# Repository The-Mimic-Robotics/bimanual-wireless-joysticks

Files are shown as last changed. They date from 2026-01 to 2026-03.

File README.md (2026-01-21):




<h2>Summary</h2>

This project enables the high-precision wireless control of MISC, two robotic arms, using Feetech STS smart motors. By utilizing a distributed architecture of ESP32 microcontrollers, the system translates physical joystick inputs into real-time robotic movement, with XBOX controller protocol emulation.

It is designed for low latency and high reliability, featuring a central hub that aggregates data from multiple peripheral devices to synchronize motor behavior across a daisy-chained serial bus.

<h2>Features</h2>

<h3>Multi-Protocol Wireless Control</h3>

Leverages **ESP-NOW** to transmit joystick data from peripheral ESP32-C3 SuperMini units to a central hub with sub-second processing latency and **Bluetooth Low Energy (BLE)** to relay the combined data to a workstation.

<h3>XBOX Protocol Emulation</h3>

The central ESP32 Node-MCU formats incoming data to impersonate standard XBOX controller protocols using **jsTest**, allowing the robotic inputs to be recognized by standard simulation and gaming software.

<h3>Daisy-Chained Smart Servos</h3>

Controls a series of 4 **Feetech STS smart motors** via a single UART interface, maximizing hardware efficiency while maintaining individual motor addressability. Only visible [here](https://projectgrid.net/museum/mimicbrach)!

<h3>Precision Calibration</h3>

Includes a dedicated calibration suite using potentiometers to record non-zero offsets and an algorithmic safety layer to enforce the unique range of motion for each specific motor.

<h3>Functional Block Architecture</h3>

Components are grouped into logical clusters (Power, Processing, IO), significantly reducing the "Spaghetti Ratsnest" effect and shortening signal paths for improved electromagnetic compatibility (EMC).

<h3>Advanced Power Filtering</h3>

Features a precision decoupling strategy with 0.1uF and 22uF local energy reservoirs placed at the physical limit of the VCC pins to prevent high-frequency noise and random system crashes.

<h3>Thermal Heat Sinking</h3>

Utilizes strategic copper pours and ground planes to act as a passive heat sink for the L7805 regulator, preventing thermal shutdown in high-current applications.

<h3>Fabrication-Ready Constraints</h3>

Incorporates strict design rules for copper-to-edge clearances and mechanical "finger space," ensuring the board is both manufacturable and usable in real-world enclosures.

<h2>Technical Implementation</h2>

The architecture is split between input capture and central processing to minimize cumulative latency:

<h3>Peripheral Input (ESP32-C3 SuperMini)</h3>

Acts as the peripheral device for reading analog joystick inputs. It handles the initial signal processing and transmits the data packets wirelessly to the hub. It also supports a serial bridge for real-time robotic arm simulations.

<h3>Central Hub (ESP32 Node-MCU)</h3>

Aggregates data from both peripheral arms, handles the logic for motor ID deduction in daisy-chained configurations, and outputs the final formatted control signals.

<h3>Hardware & Power Management</h3>

* **Communication:** UART protocol for high-speed motor telemetry.
* **Power:** Powered by a programmable DC supply outputting **7.4V @ 2A**, optimized for the peak current draw of 4 smart motors.
* **Latency Control:** Rigorous experimental tuning using 3D-printed mini robot arms to ensure 100% mirroring of user inputs.

<h3>Functional Grouping & Routing</h3>

To avoid a "Spaghetti" ratsnest, MicroNode utilizes functional block grouping. All capacitors and resistors for the ESP32 are kept in close proximity to the MCU, while the L7805 and its filter capacitors form a dedicated power block. Components are rotated to minimize crossing "ratsnest" lines, resulting in shorter, straighter traces.

<h3>Local Energy Reservoirs</h3>

Electrical stability is maintained by placing the 0.1uF decoupling capacitor as close as physically possible to the VCC pin of the ESP32. This creates the shortest possible VCC-Capacitor-Ground loop, allowing the capacitor to filter high-frequency noise effectively.

<h3>Edge Clearance Constraints</h3>

To prevent the fabrication house's router bits from clipping copper traces, a "Copper to Edge" clearance of 0.5mm (20 mils) is enforced via KiCad’s Design Rules (Board Setup > Constraints). This protects the integrity of the yellow Edge.Cuts boundary during the milling process.

<h3>Thermal Management (L7805)</h3>

The L7805 linear regulator is given "breathing room" to convert excess voltage into heat safely. Instead of smothering it between larger components, it is connected to a large Ground Plane (Copper Pour) which pulls heat away from the regulator body.

<h3>Mechanical & 3D Verification</h3>

The KiCad 3D Viewer (Alt + 3) is used to verify "Finger Space." This ensures that connectors are not placed so close together that cables cannot be plugged in, and that tall components do not obstruct mechanical access.

<h2>Installation</h2>

Clone the project repository

```bash
git clone https://github.com/The-Mimic-Robotics/bimanual-wireless-joysticks.git
```

<h3>Peripheral (ESP32-C3 SuperMini)</h3>

Install the libraries

Upload Peripheral Code

1. Connect the ESP32-C3 SuperMini.
2. Change the BOARD_ID integer value!
3. Flash the device.

<h3>Central Hub (ESP32 Node-MCU)</h3>

Install the libraries

Upload Central Hub Code

1. Connect the ESP32 Node-MCU.
2. Flash the device.

<h3>Smart Motors Controller</h3>

Install the libraries

Upload [Code](https://projectgrid.net/museum/mimicbrach)

1. Connect the desired micro-controller
2. Flash the device.

<h2>Authors</h2>

|Maintainer|Gabrel Oliveira da Silva
|---|---
|Status|Maintained/Active
|Web-Page|https://projectgrid.net
|Patch Work|https://github.com/The-Mimic-Robotics/bimanual-wireless-joysticks/commits?author=gabibdods
|SCM|https://github.com/The-Mimic-Robotics/bimanual-wireless-joysticks.git
|Files|ble_central/, ble_periph/, control_servo/, .tool-versions

|Maintainer|Ashal Patel
|---|---
|Status|Maintained/Contributing
|Web-Page|https://portfolio-website-alpha-smoky-75.vercel.app
|Patch Work|https://github.com/The-Mimic-Robotics/bimanual-wireless-joysticks/commits?author=ac-pate
|SCM|https://github.com/The-Mimic-Robotics/bimanual-wireless-joysticks.git
|Files|imu_wt61/

<h2>Album</h2>

<h3>Network of micro-controllers</h3>

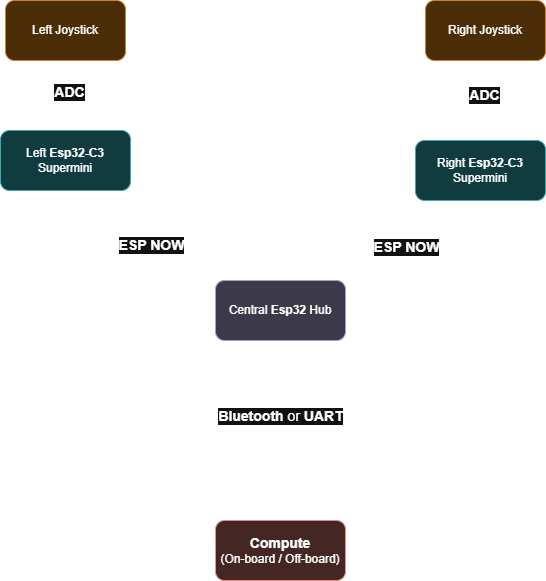
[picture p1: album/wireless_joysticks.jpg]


<h3>And more!</h3>

[Here!](https://projectgrid.net/mimicbrach)

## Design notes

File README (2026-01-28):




## Summary

This project enables the high-precision wireless control of MISC, two robotic arms, using Feetech STS smart motors. By utilizing a distributed architecture of ESP32 microcontrollers, the system translates physical joystick inputs into real-time robotic movement, with XBOX controller protocol emulation.

It is designed for low latency and high reliability, featuring a central hub that aggregates data from multiple peripheral devices to synchronize motor behavior across a daisy-chained serial bus.

## Features

### Multi-Protocol Wireless Control

Leverages **ESP-NOW** to transmit joystick data from peripheral ESP32-C3 SuperMini units to a central hub with sub-second processing latency and **Bluetooth Low Energy (BLE)** to relay the combined data to a workstation.

### BOX Protocol Emulation

The central ESP32 Node-MCU formats incoming data to impersonate standard XBOX controller protocols using **jsTest**, allowing the robotic inputs to be recognized by standard simulation and gaming software.

### Daisy-Chained Smart Servos

Controls a series of 4 **Feetech STS smart motors** via a single UART interface, maximizing hardware efficiency while maintaining individual motor addressability. Only visible [here](https://projectgrid.net/museum/mimicbrach)!

### Precision Calibration

Includes a dedicated calibration suite using potentiometers to record non-zero offsets and an algorithmic safety layer to enforce the unique range of motion for each specific motor.

### Functional Block Architecture

Components are grouped into logical clusters (Power, Processing, IO), significantly reducing the "Spaghetti Ratsnest" effect and shortening signal paths for improved electromagnetic compatibility (EMC).

### Advanced Power Filtering

Features a precision decoupling strategy with 0.1uF and 22uF local energy reservoirs placed at the physical limit of the VCC pins to prevent high-frequency noise and random system crashes.

### Thermal Heat Sinking

Utilizes strategic copper pours and ground planes to act as a passive heat sink for the L7805 regulator, preventing thermal shutdown in high-current applications.

### Fabrication-Ready Constraints

Incorporates strict design rules for copper-to-edge clearances and mechanical "finger space," ensuring the board is both manufacturable and usable in real-world enclosures.

## Technical Implementation

The architecture is split between input capture and central processing to minimize cumulative latency:

### Peripheral Input (ESP32-C3 SuperMini)

Acts as the peripheral device for reading analog joystick inputs. It handles the initial signal processing and transmits the data packets wirelessly to the hub. It also supports a serial bridge for real-time robotic arm simulations.

### Central Hub (ESP32 Node-MCU)

Aggregates data from both peripheral arms, handles the logic for motor ID deduction in daisy-chained configurations, and outputs the final formatted control signals.

### Hardware & Power Management

* **Communication:** UART protocol for high-speed motor telemetry.
* **Power:** Powered by a programmable DC supply outputting **7.4V @ 2A**, optimized for the peak current draw of 4 smart motors.
* **Latency Control:** Rigorous experimental tuning using 3D-printed mini robot arms to ensure 100% mirroring of user inputs.

### Functional Grouping & Routing

To avoid a "Spaghetti" ratsnest, MicroNode utilizes functional block grouping. All capacitors and resistors for the ESP32 are kept in close proximity to the MCU, while the L7805 and its filter capacitors form a dedicated power block. Components are rotated to minimize crossing "ratsnest" lines, resulting in shorter, straighter traces.

### Local Energy Reservoirs

Electrical stability is maintained by placing the 0.1uF decoupling capacitor as close as physically possible to the VCC pin of the ESP32. This creates the shortest possible VCC-Capacitor-Ground loop, allowing the capacitor to filter high-frequency noise effectively.

### Edge Clearance Constraints

To prevent the fabrication house's router bits from clipping copper traces, a "Copper to Edge" clearance of 0.5mm (20 mils) is enforced via KiCad’s Design Rules (Board Setup > Constraints). This protects the integrity of the yellow Edge.Cuts boundary during the milling process.

### Thermal Management (L7805)

The L7805 linear regulator is given "breathing room" to convert excess voltage into heat safely. Instead of smothering it between larger components, it is connected to a large Ground Plane (Copper Pour) which pulls heat away from the regulator body.

### Mechanical & 3D Verification

The KiCad 3D Viewer (Alt + 3) is used to verify "Finger Space." This ensures that connectors are not placed so close together that cables cannot be plugged in, and that tall components do not obstruct mechanical access.

## Installation

### Clone the project repository

```bash
git clone https://github.com/The-Mimic-Robotics/bimanual-wireless-joysticks.git
```

### Peripheral (ESP32-C3 SuperMini)

#### Install the libraries

#### Upload Peripheral Code

1. Connect the ESP32-C3 SuperMini.
2. Change the BOARD_ID integer value!
3. Flash the device.

### Central Hub (ESP32 Node-MCU)

#### Install the libraries

#### Upload Central Hub Code

1. Connect the ESP32 Node-MCU.
2. Flash the device.

### Smart Motors Controller

#### Install the libraries

#### Upload [Code](https://projectgrid.net/museum/mimicbrach)

1. Connect the desired micro-controller
2. Flash the device.

## Authors

|Maintainer|Gabrel Oliveira da Silva
|---|---
|Status|Maintained/Active
|Web-Page|https://projectgrid.net
|Patch Work|https://github.com/The-Mimic-Robotics/bimanual-wireless-joysticks/commits?author=gabibdods
|SCM|https://github.com/The-Mimic-Robotics/bimanual-wireless-joysticks.git
|Files|ble_central/, ble_periph/, control_servo/, .tool-versions

|Maintainer|Ashal Patel
|---|---
|Status|Maintained/Contributing
|Web-Page|https://portfolio-website-alpha-smoky-75.vercel.app
|Patch Work|https://github.com/The-Mimic-Robotics/bimanual-wireless-joysticks/commits?author=ac-pate
|SCM|https://github.com/The-Mimic-Robotics/bimanual-wireless-joysticks.git
|Files|imu_wt61/

## Album

### Network of micro-controllers



### And more!

[Here!](https://projectgrid.net/mimicbrach)

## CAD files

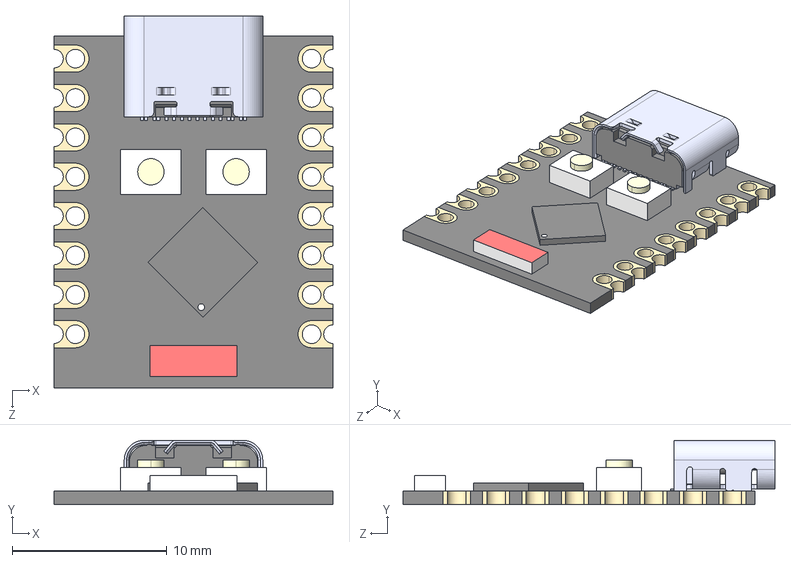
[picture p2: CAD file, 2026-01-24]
teleop_pcb/ESP32-C3_SUPERMINI_TH/ESP32-C3_SUPERMINI_TH.step
18.0 x 4.16 x 24.0 mm
Board c3mini
USB C
components (other)^ESP32-C3 SuperMini

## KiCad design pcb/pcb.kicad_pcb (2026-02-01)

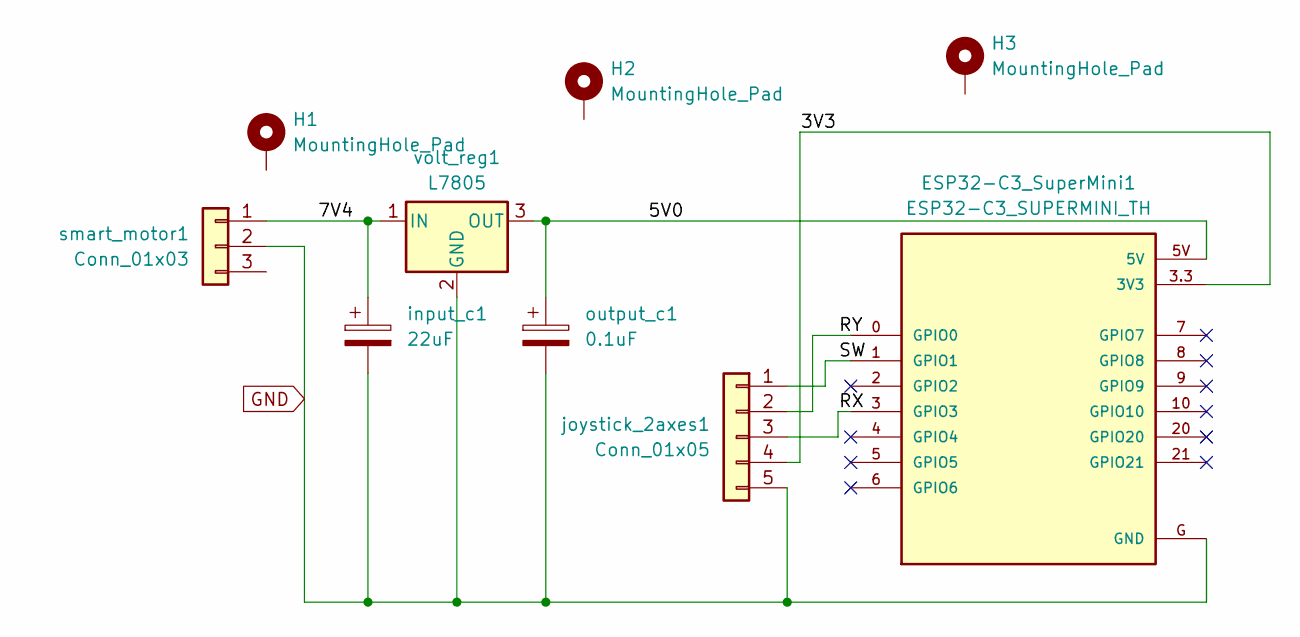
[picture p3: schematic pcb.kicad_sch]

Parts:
ESP32-C3_SuperMini1: ESP32-C3_SUPERMINI_TH; MODULE_ESP32-C3_SUPERMINI_TH
H1, H2, H3: MountingHole_Pad; MountingHole_2.5mm_Pad
input_c1: 22uF; CP_Radial_D6.3mm_P2.50mm
joystick_2axes1: Conn_01x05; PinHeader_1x05_P2.54mm_Vertical
output_c1: 0.1uF; CP_Radial_D4.0mm_P2.00mm
smart_motor1: Conn_01x03; PinHeader_1x03_P2.54mm_Vertical
volt_reg1: L7805; TO-220-3_Vertical

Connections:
/3V3: ESP32-C3_SuperMini1.3.3 (3V3), joystick_2axes1.4 (5V)
/5V0: ESP32-C3_SuperMini1.5V, output_c1.1, volt_reg1.3 (OUT)
/7V4: input_c1.1, smart_motor1.1 (7V4), volt_reg1.1 (IN)
/RX: ESP32-C3_SuperMini1.3 (GPIO3), joystick_2axes1.3 (Rx)
/RY: ESP32-C3_SuperMini1.0 (GPIO0), joystick_2axes1.2 (Ry)
/SW: ESP32-C3_SuperMini1.1 (GPIO1), joystick_2axes1.1 (SW)
GND: ESP32-C3_SuperMini1.G (GND), input_c1.2, joystick_2axes1.5 (GND), output_c1.2, smart_motor1.2 (GND), volt_reg1.2 (GND)

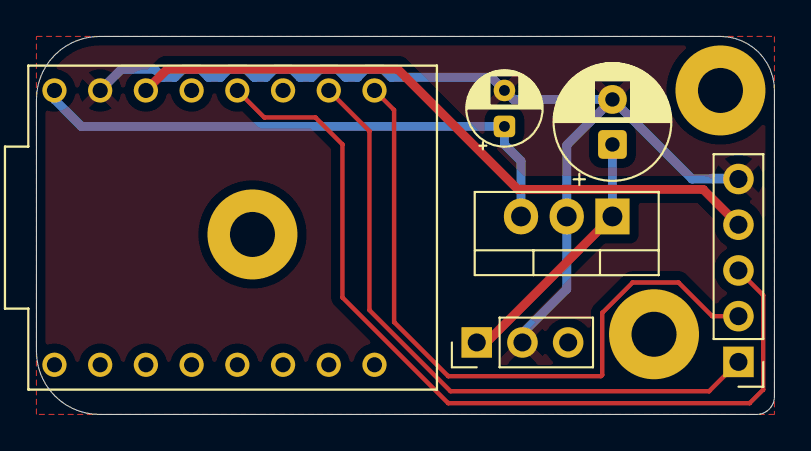
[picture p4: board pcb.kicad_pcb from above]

Board: 2 copper layers, 41.0 x 21.0 mm, 9 parts (0 on the bottom side), 7 nets.

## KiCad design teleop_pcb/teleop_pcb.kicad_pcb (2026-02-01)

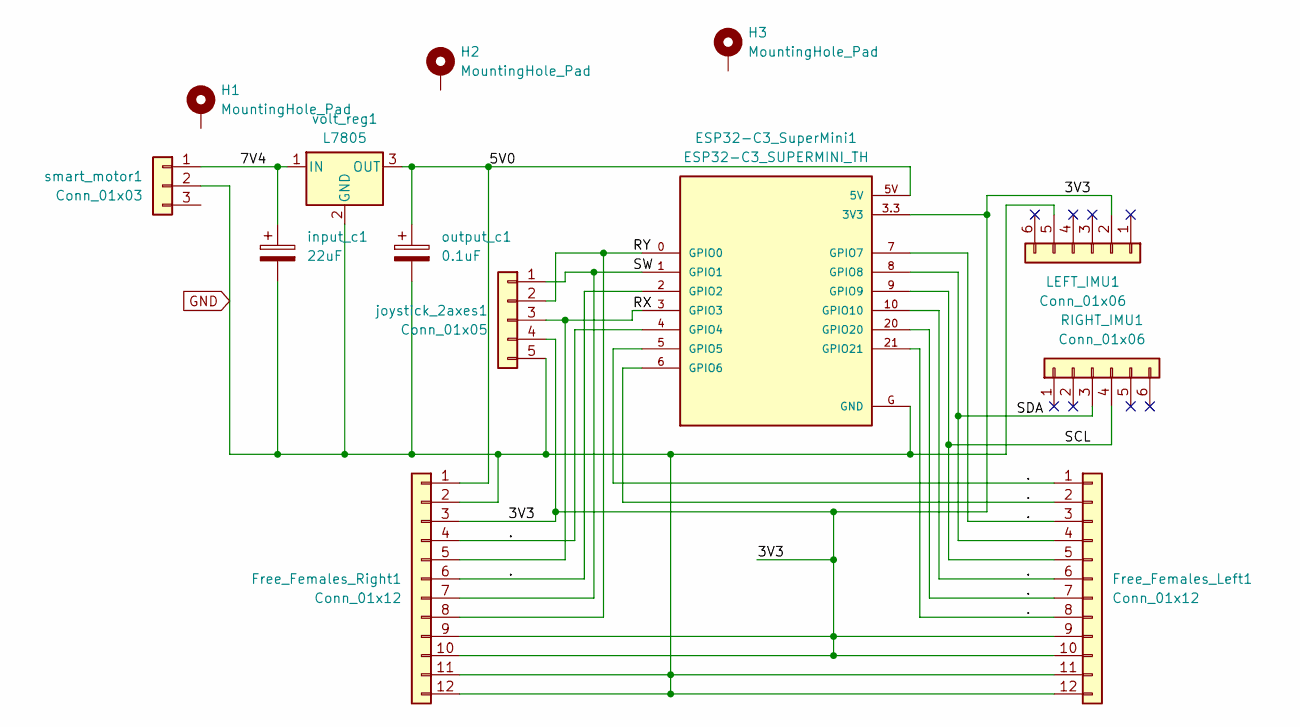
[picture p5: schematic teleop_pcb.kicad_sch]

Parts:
ESP32-C3_SuperMini1: ESP32-C3_SUPERMINI_TH; MODULE_ESP32-C3_SUPERMINI_TH
Free_Females_Left1: Conn_01x12; PinSocket_1x12_P2.54mm_Vertical
Free_Females_Right1: Conn_01x12; PinSocket_1x12_P2.54mm_Vertical
H1, H2, H3: MountingHole_Pad; MountingHole_2.5mm_Pad
LEFT_IMU1: Conn_01x06; PinSocket_1x06_P2.54mm_Vertical
RIGHT_IMU1: Conn_01x06; PinSocket_1x06_P2.54mm_Vertical
input_c1: 22uF; CP_Radial_D6.3mm_P2.50mm
joystick_2axes1: Conn_01x05; PinHeader_1x05_P2.54mm_Vertical
output_c1: 0.1uF; CP_Radial_D4.0mm_P2.00mm
smart_motor1: Conn_01x03; PinHeader_1x03_P2.54mm_Vertical
volt_reg1: L7805; TO-220-3_Vertical

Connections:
/3V3: ESP32-C3_SuperMini1.3.3 (3V3), Free_Females_Left1.9, Free_Females_Left1.10, Free_Females_Right1.3, Free_Females_Right1.9, Free_Females_Right1.10, LEFT_IMU1.2 (VCC), joystick_2axes1.4 (5V)
/5V0: ESP32-C3_SuperMini1.5V, Free_Females_Right1.1, output_c1.1, volt_reg1.3 (OUT)
/7V4: input_c1.1, smart_motor1.1 (7V4), volt_reg1.1 (IN)
/.: ESP32-C3_SuperMini1.2 (GPIO2), ESP32-C3_SuperMini1.4 (GPIO4), ESP32-C3_SuperMini1.5 (GPIO5), ESP32-C3_SuperMini1.6 (GPIO6), ESP32-C3_SuperMini1.7 (GPIO7), ESP32-C3_SuperMini1.10 (GPIO10), ESP32-C3_SuperMini1.20 (GPIO20), ESP32-C3_SuperMini1.21 (GPIO21), Free_Females_Left1.1, Free_Females_Left1.2, Free_Females_Left1.3, Free_Females_Left1.6, Free_Females_Left1.7, Free_Females_Left1.8, Free_Females_Right1.4, Free_Females_Right1.6
/RX: ESP32-C3_SuperMini1.3 (GPIO3), Free_Females_Right1.5, joystick_2axes1.3 (Rx)
/RY: ESP32-C3_SuperMini1.0 (GPIO0), Free_Females_Right1.8, joystick_2axes1.2 (Ry)
/SCL: ESP32-C3_SuperMini1.9 (GPIO9), Free_Females_Left1.5, RIGHT_IMU1.4
/SDA: ESP32-C3_SuperMini1.8 (GPIO8), Free_Females_Left1.4, RIGHT_IMU1.3
/SW: ESP32-C3_SuperMini1.1 (GPIO1), Free_Females_Right1.7, joystick_2axes1.1 (SW)
GND: ESP32-C3_SuperMini1.G (GND), Free_Females_Left1.11, Free_Females_Left1.12, Free_Females_Right1.2, Free_Females_Right1.11, Free_Females_Right1.12, LEFT_IMU1.5 (GND), input_c1.2, joystick_2axes1.5 (GND), output_c1.2, smart_motor1.2 (GND), volt_reg1.2 (GND)

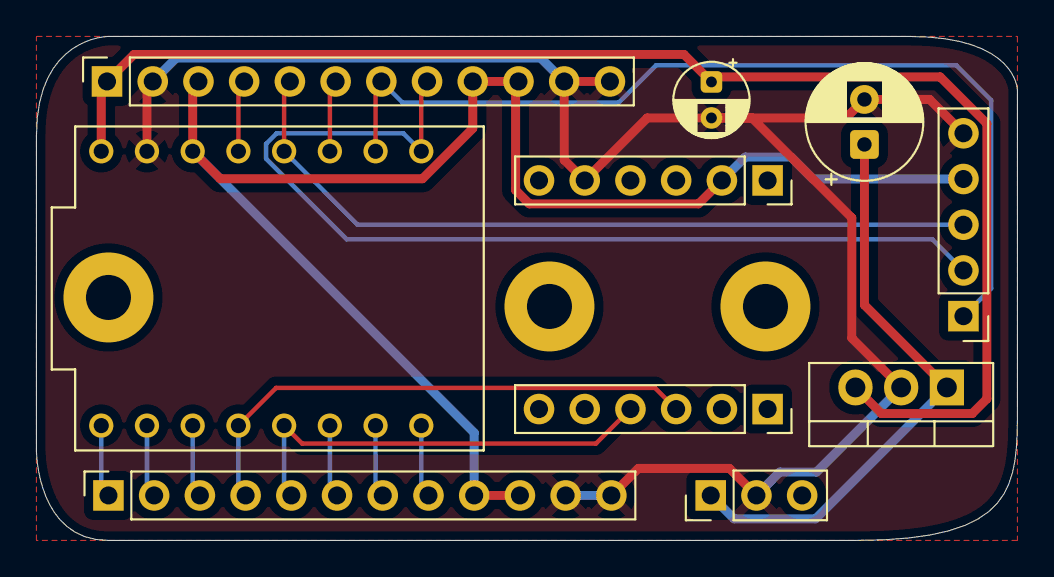
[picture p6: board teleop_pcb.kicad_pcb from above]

Board: 2 copper layers, 54.5 x 28.0 mm, 13 parts (0 on the bottom side), 10 nets.

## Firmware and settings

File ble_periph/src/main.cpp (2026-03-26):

#include <Arduino.h>
#include <esp_now.h>
#include <WiFi.h>

#define DEADZONE 400
#define ADC_CENTER 2048

const uint8_t XPOS_PIN = 3;
const uint8_t YPOS_PIN = 0;
const uint8_t PUSH_PIN = 1;

typedef struct struct_message
{
  int id;
  int x;
  int y;
  int push;
} struct_message;

struct_message myData;
uint8_t broadcastAddress[] = {0xFF, 0xFF, 0xFF, 0xFF, 0xFF, 0xFF};

volatile bool deliverySuccess = false;

void OnDataSent(const uint8_t *mac_addr, esp_now_send_status_t status)
{
  if (status == ESP_NOW_SEND_SUCCESS)
  {
    deliverySuccess = true;
    digitalWrite(8, 0); //LED_PIN
  } else
  {
    deliverySuccess = false;
    digitalWrite(8, 1); //LED_PIN
  }
}

void setup() {
  pinMode(8, OUTPUT); //LED_PIN

  WiFi.mode(WIFI_STA);

  if (esp_now_init() != ESP_OK) return;

  esp_now_register_send_cb((esp_now_send_cb_t)OnDataSent);

  esp_now_peer_info_t peerInfo;
  memcpy(peerInfo.peer_addr, broadcastAddress, 6);
  peerInfo.channel = 0;
  peerInfo.encrypt = false;

  if (esp_now_add_peer(&peerInfo) != ESP_OK) return;

  analogReadResolution(12);

  pinMode(XPOS_PIN, INPUT);
  pinMode(YPOS_PIN, INPUT);
  pinMode(PUSH_PIN, INPUT_PULLUP);
}

int applyDeadzone(int value) {
  if (abs(value - ADC_CENTER) < DEADZONE) {
    return ADC_CENTER;
  }
  return value;
}

void loop() {
  int rawX = applyDeadzone(analogRead(XPOS_PIN));
  int rawY = applyDeadzone(analogRead(YPOS_PIN));

  // right hand
  //myData.id = 1;
  //myData.x = map(rawX, 0, 4095, 32767, 0);
  //myData.y = map(rawY, 0, 4095, 0, 32767);
 
  // left hand
  myData.id = 2;
  myData.x = map(rawX, 0, 4095, 32767, 0);
  myData.y = map(rawY, 0, 4095, 32767, 0);

  myData.push = digitalRead(PUSH_PIN);

  esp_err_t result = esp_now_send(broadcastAddress, (uint8_t *) &myData, sizeof(myData));

  delay(5);
}

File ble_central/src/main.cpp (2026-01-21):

#include <Arduino.h>
#include <esp_now.h>
#include <WiFi.h>

#include <NimBLEDevice.h>
#include <BleGamepad.h>
#include <BleGamepadConfiguration.h>

BleGamepad bleGamepad("ESP32 Dual Stick", "Maker", 100);

typedef struct struct_message
{
  int id;
  int x;
  int y;
  int push;
} struct_message;

struct_message incomingData;

volatile long msgX1 = 0, msgY1 = 0, msgB1 = 0;
volatile long msgX2 = 0, msgY2 = 0, msgB2 = 0;

unsigned long lastRecvTime1 = 0;
unsigned long lastRecvTime2 = 0;
const unsigned long TIMEOUT_MS = 2000;

TaskHandle_t Task0;

void OnDataRecv(const uint8_t * mac, const uint8_t *incomingDataPtr, int len)
{
  memcpy(&incomingData, incomingDataPtr, sizeof(incomingData));

  if (incomingData.id == 1)
  {
    msgX1 = incomingData.x;
    msgY1 = incomingData.y;
    msgB1 = incomingData.push;
    lastRecvTime1 = millis();
  } else
  if (incomingData.id == 2)
  {
    msgX2 = incomingData.x;
    msgY2 = incomingData.y;
    msgB2 = incomingData.push;
    lastRecvTime2 = millis();
  }
}

void espNowTask(void * pvParameters)
{
  WiFi.mode(WIFI_STA);

  if (esp_now_init() != ESP_OK)
  {
    Serial.println("Error initializing ESP-NOW");
    vTaskDelete(NULL);
  }

  esp_now_register_recv_cb(OnDataRecv);

  while (1)
  {
    unsigned long currentTime = millis();
    bool connected1 = (currentTime - lastRecvTime1) < TIMEOUT_MS;
    bool connected2 = (currentTime - lastRecvTime2) < TIMEOUT_MS;

    if (connected1 && connected2)
    {
      digitalWrite(2, 1); //LED_PIN
    } else
    {
      digitalWrite(2, 0); //LED_PIN
    }

    vTaskDelay(10 / portTICK_PERIOD_MS);
  }
}

void setup() {
  Serial.begin(115200);

  pinMode(2, OUTPUT); //LED_PIN
  digitalWrite(2, 0); //LED_PIN

  xTaskCreatePinnedToCore(
    espNowTask,   // task function
    "ESPNowTask", // name of task
    10000,        // stack size of task
    NULL,         // parameter of the task
    1,            // priority of the task
    &Task0,       // task handle
    0             // execute on core 0, loop() always runs on Core 1
  );

  BleGamepadConfiguration bleGamepadConfig;
  bleGamepadConfig.setAutoReport(false);
  bleGamepadConfig.setControllerType(CONTROLLER_TYPE_GAMEPAD);
  bleGamepad.begin(&bleGamepadConfig);

  while (msgB1 == 1 || msgB2 == 1); // safeguard: might need to put this in loop() if not work
}

void loop() {
  if (bleGamepad.isConnected())
  {
    bleGamepad.setAxes(msgX1, msgY1, msgX2, msgY2, 0, 0, 0, 0);

    if (msgB1 == 0) bleGamepad.press(BUTTON_1);
    else bleGamepad.release(BUTTON_1);

    if (msgB2 == 0) bleGamepad.press(BUTTON_2);
    else bleGamepad.release(BUTTON_2);

    bleGamepad.sendReport();
  }

  delay(20);
}

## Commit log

2026-01-04 dataflow change: 2 peripherals sending joystick data to central device
2026-01-15 pin 3 of ESP32-C3 SuperMini is faulty, switch to pin 0
2026-01-19 fixed inversed axes of left joystick display
    [main.cpp]
2026-01-20 ADDS: IMU sample code for quat. data over I2C
2026-01-21 first attempt at PCB designing
    [pcb-B_Cu.gbr, pcb-B_Mask.gbr, pcb-B_Paste.gbr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]
2026-01-21 removed tracking for pcb/pcb-backups/
2026-01-21 added ground plane on front and back of pcb
    [pcb-B_Cu.gbr, pcb-B_Mask.gbr, pcb-B_Paste.gbr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]
2026-01-24 new pcb with custom footprint
    [ESP32-C3_SUPERMINI_TH.step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]
2026-01-24 added rounded edges, mounting holes and legend on pcb
    [pcb-B_Cu.gbr, pcb-B_Mask.gbr, pcb-B_Paste.gbr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]
2026-01-28 teleop pcb with place for IMU
    [teleop_pcb-B_Cu.gbr, teleop_pcb-B_Mask.gbr, teleop_pcb-B_Paste.gbr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]
2026-02-01 added pin socket rows for teleop pcb
    [ESP32-C3_SUPERMINI_TH.step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]
2026-02-28 periph sending BLE signals to specific MAC of central hub does not work
    [main.cpp]
